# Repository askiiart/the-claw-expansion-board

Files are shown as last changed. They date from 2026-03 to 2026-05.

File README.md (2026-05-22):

# The Claw Expansion Board

## WARNING: EXTREME HEAT

This design accidentally used an LDO, which can lead to up to ~240 watts of excess heat being generated. Do not use this as it is now! Change the design to use a buck converter instead.

---

Would recommmend swapping it out for a XL4016E1. Will be updated with that eventually.

An expansion board to support further modding for my printer I'm desinging for Blueprint. The goals of this are:

- Power output rails on 24V, 12V, and 5V
- Power + I2C expansion port
- Laser (power/GND/PWM) port
- PNP (vacuum PWR/GND ; solenoid PWR/GND) port
- MOSFET to turn bed on/off, rather than depending on messy external setup
- Able to handle the maximum current (25A, 7.5A for buck converters) anywhere

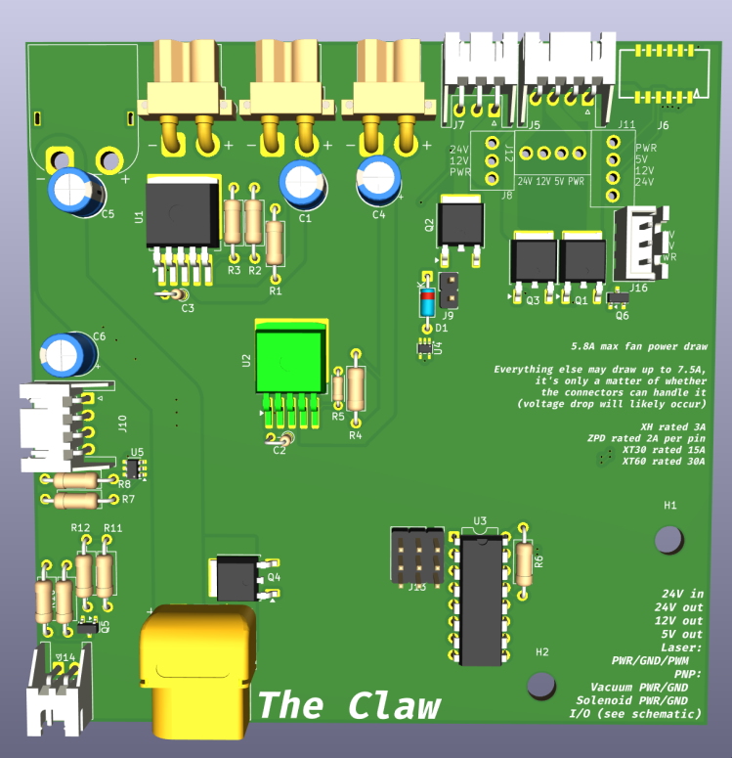
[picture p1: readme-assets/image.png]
A 3D model of the PCB


## Parts

|Item |Price |Quantity|Link |Total Cost|Notes |
|---|---|---|---|---|---|
|COS29752WU (LDO regulator) |$2.10 |2 |https://www.lcsc.com/product-detail/C41428569.html |$4.20 | |
|XD8574AP (I/O expander) |$0.57 |1 |https://www.lcsc.com/product-detail/C561268.html |$0.57 | |
|DB125-2.54-4P-GN-S (4P screw term)  |$0.40 |2 |https://www.lcsc.com/product-detail/C918122.html |$0.80 | |
|DB125-2.54-3P-GN-S (3P screw term)  |$0.33 |1 |https://www.lcsc.com/product-detail/C918121.html |$1.67 | |
|MS50N06 (50A NMOS) |$0.11 |4 |https://www.lcsc.com/product-detail/C2902884.html |$0.57 | |
|AO3400A (5.8A NMOS) |$0.03 |1 |https://www.lcsc.com/product-detail/C347475.html |$0.65 | |
|BSS84 (PMOS) |$0.01 |1 |https://www.lcsc.com/product-detail/C50386320.html |$0.55 | |
|PZ254-3-03-Z-2.5-G0 (3x3 pins) |$0.21 |1 |https://www.lcsc.com/product-detail/C7429377.html |$1.03 | |
|XT30PW-F20.G.Y (XT30 headers) |$0.33 |3 |https://www.lcsc.com/product-detail/C2913282.html |$1.00 | |
|XT60PW-F (XT60 female headers) |$0.55 |1 |https://www.lcsc.com/product-detail/C428722.html |$0.55 | |
|XT60PW-M (XT60 male header) |$0.52 |1 |https://www.lcsc.com/product-detail/C98732.html |$0.52 | |
|S3B-XH-A(LF)(SN) (XH 3P R/A) |$0.09 |1 |https://www.lcsc.com/product-detail/C157928.html |$0.92 | |
|S4B-XH-A-1(LF)(SN) (XH 4P R/A) |$0.15 |2 |https://www.lcsc.com/product-detail/C157925.html |$0.77 | |
|SM12B-ZPDSS-TF(LF)(SN) (ZPD 12P R/A)|$0.80 |1 |https://www.lcsc.com/product-detail/C265342.html |$0.80 | |
|ZPDR-12V-S (ZPD 12P housing) |$0.34 |1 |https://www.lcsc.com/product-detail/C566944.html |$1.68 | |
|HC-ZHD-T-05 (ZPD crimps) |$0.02 |12 |https://www.lcsc.com/product-detail/C20539070.html |$0.96 | |
|JST XHP-3 (XH 3P housing) |$0.02 |2 |https://www.lcsc.com/product-detail/C144402.html |$0.46 | |
|JST XHP-4 (XH 4P housing) |$0.02 |2 |https://www.lcsc.com/product-detail/C144403.html |$0.45 | |
|ZX-XH2.54-DZ (XH crimps) |$0.01 |14 |https://www.lcsc.com/product-detail/C7462731.html |$0.42 | |
|B3B-XH-A(LF)(SN) (XH 3P vertical) |$0.05 |1 |https://www.lcsc.com/product-detail/C144394.html |$0.54 | |
|ERJ1EM680E09OT (68uF caps) |$0.03 |4 |https://www.lcsc.com/product-detail/C106558.html |$0.67 |MUST be aluminum electrolytic caps, do NOT replace with ceramic|
|178MU0006 (0.1uF caps) |$0.01 |2 |https://www.lcsc.com/product-detail/C5632430.html |$0.69 | |
|MF1/4W-10K±1%-ST52 (10k resistor) |$0.01 |7 |https://www.lcsc.com/product-detail/C2903232.html |$0.59 |All resistors are highly accurate due to setting LDO regulators|
|MF1/4W-8K2±1%-ST52 (8.2k resistor)  |$0.00 |1 |https://www.lcsc.com/product-detail/C2848599.html |$0.49 | |
|MF1/8W-3K3±1%-ST52 (3.3k resistor)  |$0.01 |1 |https://www.lcsc.com/product-detail/C2903352.html |$0.50 | |
|MF1/4W-1K±1%-ST52 (1k resistor) |$0.01 |1 |https://www.lcsc.com/product-detail/C2903245.html |$0.56 | |
|MF1/4W-470Ω±1% T (470 resistor) |$0.01 |1 |https://www.lcsc.com/product-detail/C119317.html |$0.58 | |
|1N4148TR (diode) |$0.02 |1 |https://www.lcsc.com/product-detail/C84410.html |$0.80 | |
|2.54mm jumpers |$0.01 |4 |https://www.lcsc.com/product-detail/C2998928.html |$0.44 | |
|TMP100NA/3K (temp sensor) |$0.46 |1 |https://www.lcsc.com/product-detail/C31810.html |$0.46 | |
|9733 24V fan |$6.39 |1 |https://www.aliexpress.us/item/3256804645826698.html |$6.39 | |
|Wire crimping tool |$15.99|1 |https://www.amazon.com/Crimping-Amliber-Connectors-Electrical-Terminals/dp/B0D1FR76Q7|$15.99 | |
| | | | | | |
|Subtotal | | | |$47.28 | |
| | | | | | |
|JLCPCB | | | |$7.30 | |
|LCSC shipping | | | |$14.56 | |
| | | | | | |
|Total | | | |$74.84 | |

## Notes

- **The case will be made by hand out of wood**, not 3D printed, due to potential for high temperatures. As such there is obviously no CAD model.
- **XT60 polarity is reversed!!!** I don't have the time (or energy) to redo the entire board right now, but I may redo it later.
  - XT30 has been fixed, that does not apply here
  - BOM may change slightly, as when I fix that I will make the 24V input male. Cost should be slightly lower.
- Some 3D models don't exist, and so those components aren't in the render.

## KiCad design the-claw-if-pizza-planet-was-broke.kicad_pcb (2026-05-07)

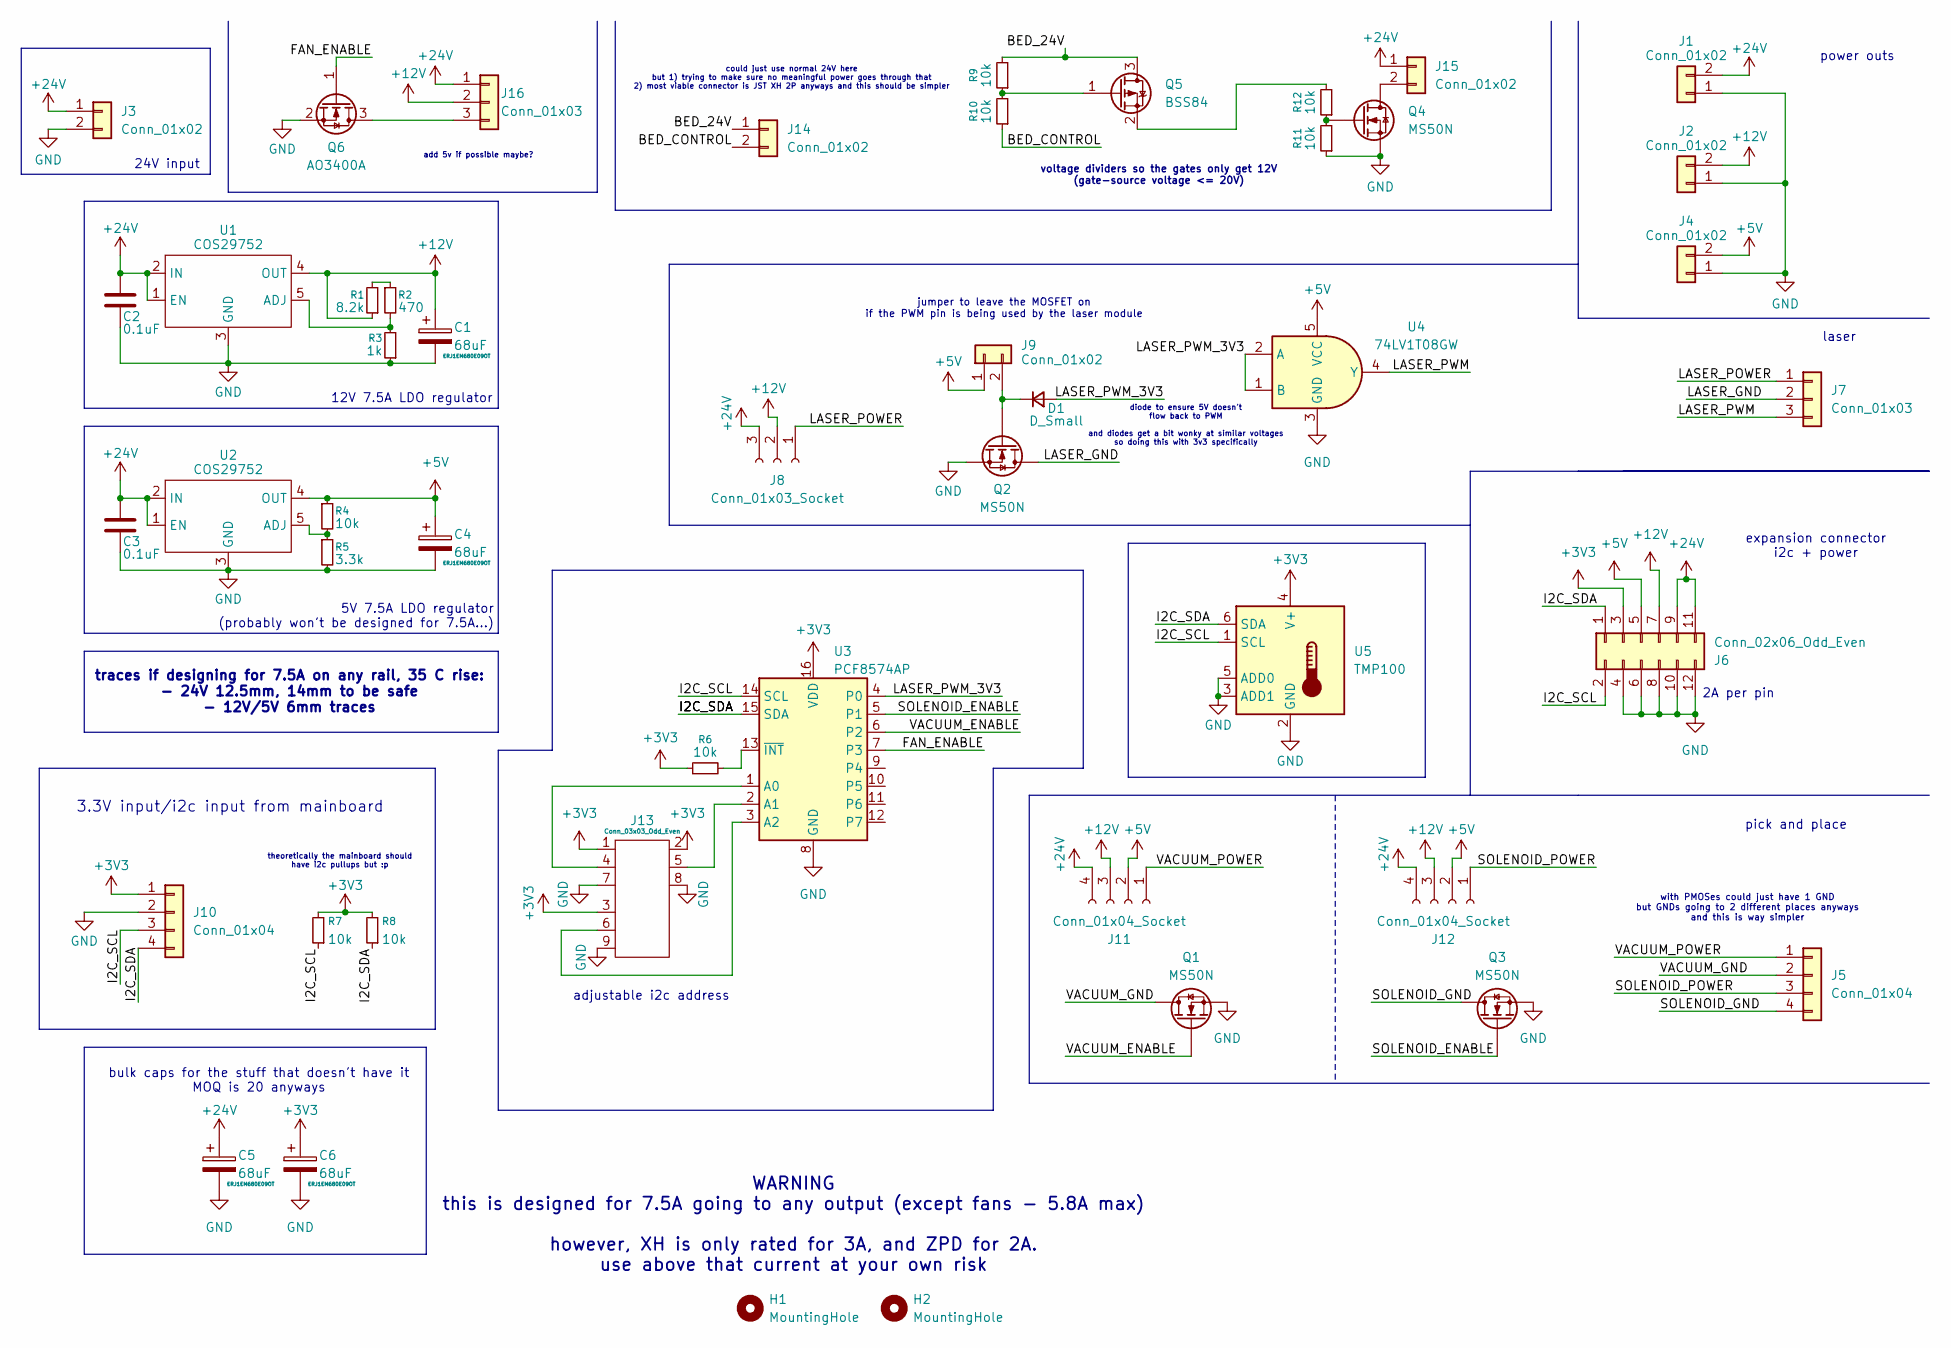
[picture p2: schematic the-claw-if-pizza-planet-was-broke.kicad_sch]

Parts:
C1, C4, C5, C6: 68uF; CP_Radial_D6.3mm_P2.50mm
C2, C3: 0.1uF; R_Axial_DIN0204_L3.6mm_D1.6mm_P2.54mm_Vertical
D1: D_Small; D_DO-35_SOD27_P7.62mm_Horizontal
H1, H2: MountingHole; MountingHole_4.3mm_M4
J1, J2, J4: Conn_01x02; AMASS_XT30PW-F_1x02_P2.50mm_Horizontal
J3: Conn_01x02; AMASS_XT60PW-M_1x02_P7.20mm_Horizontal
J5, J10: Conn_01x04; JST_XH_S4B-XH-A-1_1x04_P2.50mm_Horizontal
J6: Conn_02x06_Odd_Even; CONN-SM12B-ZPDSS-TF
J7: Conn_01x03; JST_XH_S3B-XH-A_1x03_P2.50mm_Horizontal
J8: Conn_01x03_Socket; DB125-2.54-3P
J9: Conn_01x02; PinHeader_1x02_P2.54mm_Vertical
J11, J12: Conn_01x04_Socket; DB125-2.54-4P
J13: Conn_03x03_Odd_Even; PinHeader_3x03_P2.54mm_Vertical
J14: Conn_01x02; JST_XH_S2B-XH-A-1_1x02_P2.50mm_Horizontal
J15: Conn_01x02; AMASS_XT60PW-F_1x02_P7.20mm_Horizontal
J16: Conn_01x03; JST_XH_B3B-XH-A_1x03_P2.50mm_Vertical
Q1, Q2, Q3, Q4: MS50N; TO-252-2
Q5: BSS84; SOT-23
Q6: AO3400A; SOT-23
R1: 8.2k; R_Axial_DIN0207_L6.3mm_D2.5mm_P10.16mm_Horizontal
R2: 470; R_Axial_DIN0207_L6.3mm_D2.5mm_P10.16mm_Horizontal
R3: 1k; R_Axial_DIN0207_L6.3mm_D2.5mm_P10.16mm_Horizontal
R4, R6, R7, R8, R9, R10, R11, R12: 10k; R_Axial_DIN0207_L6.3mm_D2.5mm_P10.16mm_Horizontal
R5: 3.3k; R_Axial_DIN0204_L3.6mm_D1.6mm_P5.08mm_Horizontal
U1, U2: COS29752; TO-263-5_TabPin3
U3: PCF8574AP; DIP-16_W7.62mm
U4: 74LV1T08GW; SOT-353_SC-70-5
U5: TMP100; SOT-23-6

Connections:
+3V3: C6.1, J6.3, J10.1, J13.1, J13.2, J13.3, R6.1, R7.2, R8.2, U3.16 (VDD), U5.4 (V+)
+5V: C4.1, J4.2, J6.5, J9.1, J11.2, J12.2, R4.1, U2.4 (OUT), U4.5 (VCC)
+12V: C1.1, J2.2, J6.7, J8.2, J11.3, J12.3, J16.2, R1.1, U1.4 (OUT)
+24V: C2.2, C3.2, C5.1, J1.2, J3.1, J6.9, J6.11, J8.3, J11.4, J12.4, J15.1, J16.1, U1.1 (EN), U1.2 (IN), U2.1 (EN), U2.2 (IN)
/BED_24V: J14.1, Q5.3 (D), R9.2
/BED_CONTROL: J14.2, R10.1
/FAN_ENABLE: Q6.1 (G), U3.7 (P3)
/I2C_SCL: J6.2, J10.3, R7.1, U3.14 (SCL), U5.1 (SCL)
/I2C_SDA: J6.1, J10.4, R8.1, U3.15 (SDA), U5.6 (SDA)
/LASER_GND: J7.2, Q2.2 (D)
/LASER_POWER: J7.1, J8.1
/LASER_PWM: J7.3, U4.4 (Y)
/LASER_PWM_3V3: D1.2 (A), U3.4 (P0), U4.1 (B), U4.2 (A)
/SOLENOID_ENABLE: Q3.1 (G), U3.5 (P1)
/SOLENOID_GND: J5.4, Q3.2 (D)
/SOLENOID_POWER: J5.3, J12.1
/VACUUM_ENABLE: Q1.1 (G), U3.6 (P2)
/VACUUM_GND: J5.2, Q1.2 (D)
/VACUUM_POWER: J5.1, J11.1
GND: C1.2, C2.1, C3.1, C4.2, C5.2, C6.2, J1.1, J2.1, J3.2, J4.1, J6.4, J6.6, J6.8, J6.10, J6.12, J10.2, J13.7, J13.8, J13.9, Q1.3 (S), Q2.3 (S), Q3.3 (S), Q4.3 (S), Q6.2 (S), R3.1, R5.2, R11.1, U1.3 (GND), U2.3 (GND), U3.8 (GND), U4.3 (GND), U5.2 (GND), U5.3 (ADD1), U5.5 (ADD0)
unnamed: D1.1 (K), J9.2, Q2.1 (G)
unnamed: J15.2, Q4.2 (D)
unnamed: J16.3, Q6.3 (D)
unnamed: Q4.1 (G), R11.2, R12.1
unnamed: Q5.1 (G), R9.1, R10.2
unnamed: Q5.2 (S), R12.2
unnamed: R1.2, R2.1
unnamed: R2.2, R3.2, U1.5 (ADJ)
unnamed: R4.2, R5.1, U2.5 (ADJ)
unnamed: J13.4, U3.1 (A0)
unnamed: J13.5, U3.2 (A1)
unnamed: J13.6, U3.3 (A2)
unnamed: R6.2, U3.13 (~INT)

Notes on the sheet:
power outs
traces if designing for 7.5A on any rail, 35 C rise: - 24V 12.5mm, 14mm to be safe - 12V/5V 6mm traces
WARNING this is designed for 7.5A going to any output (except fans - 5.8A max) however, XH is only rated for 3A, and ZPD for 2A. use above that current at your own risk
pick and place
laser
diode to ensure 5V doesn't flow back to PWM and diodes get a bit wonky at similar voltages so doing this with 3v3 specifically
voltage dividers so the gates only get 12V (gate-source voltage <= 20V)
could just use normal 24V here but 1) trying to make sure no meaningful power goes through that 2) most viable connector is JST XH 2P anyways and this should be simpler
5V 7.5A LDO regulator (probably won't be designed for 7.5A...)
3.3V input/i2c input from mainboard
12V 7.5A LDO regulator
with PMOSes could just have 1 GND but GNDs going to 2 different places anyways and this is way simpler
theoretically the mainboard should have i2c pullups but :p
jumper to leave the MOSFET on if the PWM pin is being used by the laser module
24V input
expansion connector i2c + power
adjustable i2c address
bulk caps for the stuff that doesn't have it MOQ is 20 anyways
add 5v if possible maybe?
2A per pin

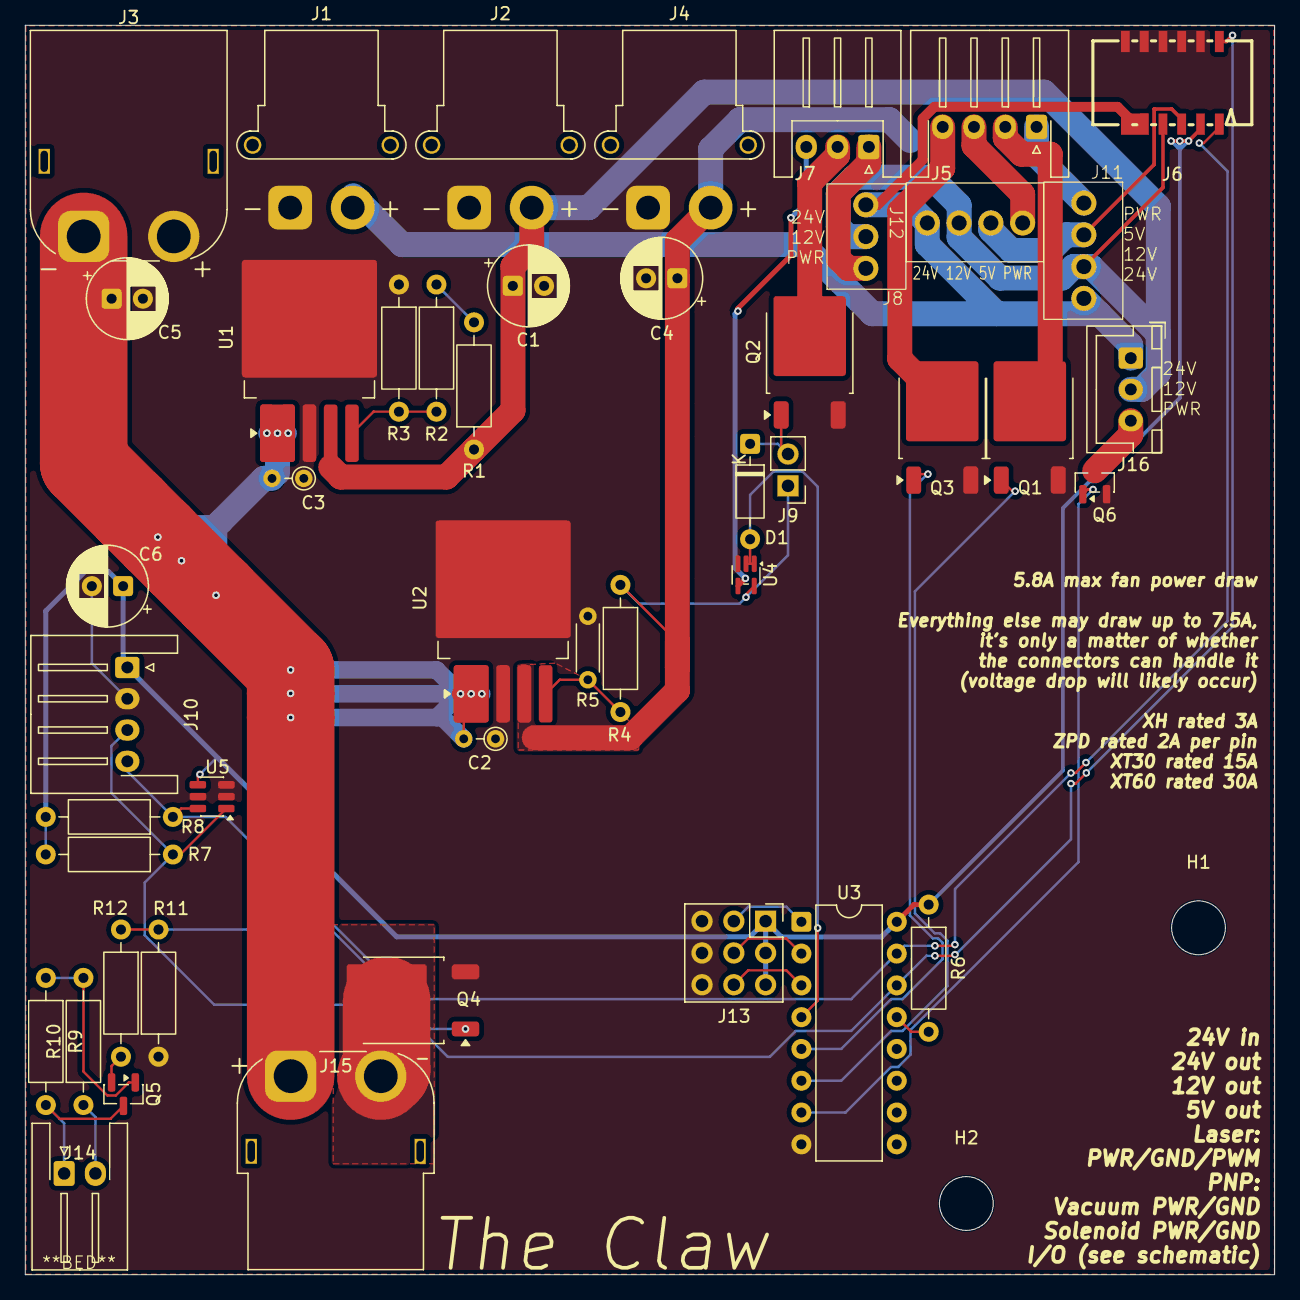
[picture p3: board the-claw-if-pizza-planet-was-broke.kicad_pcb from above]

Board: 2 copper layers, 99.8 x 99.8 mm, 48 parts (0 on the bottom side), 33 nets.

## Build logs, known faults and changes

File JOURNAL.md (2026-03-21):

## 2/14/2026 - Looked into lasers and stuff, anadapter board for connectors

*1.5 hours*

I'm aiming to have easy compatibility with lasers, with as little rewiring to switch out tools as possible, so I'm planning to have a board to adapt whatever's on the motherboard to easy wiring - for example, BL-touch to a single 5-pin connector, 2/3-pin laser to VDD + GND with PWM handled via a MOSFET on the board itself (will be 3 pin to support lasers that have PWM, can just use 2 out of 3 pins for standalone lasers), and connector for vacuum pump going to HE3.

Will also have 12/24V jumpers and buck converter for either voltage (for laser and vacuum pump), and will have an io expander connected via i2c for GPIO. Will also add general 12/24V power terminals for whatever.



Also some general resources relating to this cuz why not

- Octopus wiki thing: <https://global.bttwiki.com/Octopus.html>
- 3rd party diagram: <https://gadgetangel.org/build/electrical/images/BIGTREETECH-Octopus-1.1-color-PIN.pdf>
- Git repo (with manual and stuff): <https://github.com/bigtreetech/BIGTREETECH-OCTOPUS-V1.0>

## 2/21/2026 - Figured out pinout of the PCB

*3.5 hours*

So uh after like forever I figured out the pinout of the PCB. JST ZPD is quite niche but will work perfectly, and isn't so niche that it's too difficult to find replacements, hence going with that for GPIO/I2C + power after much deliberation. LCSC's out of stock for female right-angle XT30 connectors, so instead I'm having to go with XT60, hence I'm having to make the GPIO connector much smaller. 26 pin *would* have fit (just barely), and would've allowed for 16 pins + i2c + 3.3/5/12/24V power, but XT60, so instead I'm having to reduce it down. 10 pin would've been fine - no GPIO, just i2c and power - but LCSC doesn't have those so I figured I might as well make it 12 pin and add another 24V pin for 4A total.

(also for context regarding the high pin count, every power pin has a matching GND pin so that's not limiting this, with just 1 it would be a max 2A power draw across everything)

(i also removed 2+2 laser support to clear up room - can rewire that very easily anyways)



## 2026-03-18 - Looked into alternative DC-DC voltage regulators and connectors, added more parts such as MOSFETs

*4 hours*

I looked into alternative DC-DC voltage regulators - TO-220-5 buck converters are available, however that would mean far more supporting circuitry, so it's not worth it imo.

However, I also need solenoid control for pick and place, which requires a larger connector. To do this I redesigned the board to use a [JST ZPD 10 pin connector](https://www.digikey.com/en/products/detail/jst-sales-america-inc/SM10B-ZPDSS-TF/2472584) rather than 12 pin.

As for voltage selection for laser, the easiest way seems to be to use [screw terminals](https://www.lcsc.com/product-detail/C918122.html) and have wires jumping between them. Normal jumpers can't exactly handle 7.5 amps (nor can 0 ohm resistors). However, for the vacuum (and certainly the solenoid), those will be under 2 amp, so those can use jumper wires... though that won't actually be much smaller, so I'll probably just use screw terminals anyways.

Additionally, voltage selection will have to not be an option - level shifting above 5V is difficult, and given 5V will never be above the valid voltage range, it will only be set to output 5V.

Regarding the MOSFETs, given the low frequency (500Hz to 25kHz for laser), it's easy to find [a good MOSFET](https://www.lcsc.com/product-detail/C2902884.html). For the PNP stuff, a P-channel MOSFET controlled by a BJT + pullups would be *ideal* (increase in heat aside), but given wiring the PNP head/vacuum will be much cleaner with 2 separate GNDs, heat has a remote chance of being a concern, and this is much easier, I'm going with just using NMOSes on the vacuum and solenoid.

## 2026-03-19A - Added I/O expander, finished up schematic

*2 hours*

Pretty simple, just added the I/O expander and finished the few bits of the schematic. I'm just using pin headers and jumpers to set the I/O expander address - which is already pretty overkill but who cares :p

I also went through and selected components, nothing too interesting there, sticking with through-hole when possible though for ease of assembly - space isn't much of a concern here.

## 2026-03-19B - Added MOSFET for external bed control

*1.5 hours*

This is as good a place as any to put the bed MOSFET, so why not. Plus it actually need supporting circuitry sooooo it really need a PCB anyways. Regardless, I checked out [this](https://frank26080115.github.io/Bones-3D-Printer/other_pages/externalmosfet.html) blog post on how to use an external bed MOSFET to make sure I'm actually doing it competently. Anyways, just using

MOSFETs and to some extent voltage dividers and electricity in general confuse me so this took far longer than it should have and my brain nearly combusted. But uh yay done with that.



## 2026-03-19B - Routed PCB

*3 hours*

Took forever but I routed the PCB. Had to make custom symbols for the NMOSes so they'd work with the footprint properly, but it wasn't too bad. Also wow I love filling areas, very helpful.

Oh also I was using inner layer trace widths so I had to redo that. Much more viable with external layers.

The bed control area (many fills):



...for how long this took it feels like there should be more to write, but no routing is just kinda boring. okay byeeeeeeeeeeeeeeeee

## 2026-03-20A - Fix bed control, add cooling, reroute PCB

*4.5 hours*

Needed to fix the bed control, which was simple enough. However, two issues:

1. The PSU doesn't have enough power outputs, so the board and bed have to share one connection.
2. With this new design with all the board's power running through one XT60 plug, it's very difficult to run that much power. To hopefully alleviate some of the heat, I will be adding a fan - found [this](https://www.aliexpress.us/item/3256804645826698.html) (7515 12V) and it seems to be a good fit.

This design can handle 15A easily (the power draw of the bed), 20A with a bit of heat, and 25A (the PSU's max) if I'm being *really* adventurous. But it's nearly impossible to max out every rail simultaneously, so just above 15A is probably the max this will ever reach.



## 2026-03-20B - make BOM

*1 hour*

This is taking forever and is such a pain and libreoffice in its amazingness decided to make all the links the same so I'm redoing that now.

---

Note: sorry if my journals seem a bit odd, originally they were part of the main printer project on Blueprint before being split off to a separate project. I will be leaving a reviewer note to subtract 5 hours from the journal entries being moved.

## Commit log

2026-03-19 initial commit - schematic done
    [the-claw-if-pizza-planet-was-broke.kicad_pcb, the-claw-if-pizza-planet-was-broke.kicad_sch]
2026-03-20 update with finished(?) pcb
    [the-claw-if-pizza-planet-was-broke.kicad_pcb, the-claw-if-pizza-planet-was-broke.kicad_sch]
2026-03-21 fix a bunch of stuff
    [the-claw-if-pizza-planet-was-broke.kicad_pcb, the-claw-if-pizza-planet-was-broke.kicad_sch]
2026-03-21 add 3d models
    [the-claw-if-pizza-planet-was-broke.kicad_pcb]
2026-03-21 give XT30 hrt
    [the-claw-if-pizza-planet-was-broke.kicad_pcb, the-claw-if-pizza-planet-was-broke.kicad_sch]
2026-03-21 add BOM and stuff
    [BOM.csv, BOM.xlsx]
2026-03-21 fix BOM links
    [BOM.csv, BOM.xlsx]
2026-05-07 update w/ XT60 + silkscreen improvement
    [BOM.csv, BOM.xlsx, the-claw-if-pizza-planet-was-broke.kicad_pcb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]
2026-05-14 add recommended buck converter
